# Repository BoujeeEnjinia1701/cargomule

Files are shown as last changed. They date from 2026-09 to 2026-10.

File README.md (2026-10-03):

# CargoMule

     

**Area:** Mobility and Logistics · **TRL:** 3 of 9 (proof of concept on paper) · **Value-engineering target:** $1,000 USD (a hypothetical control target, not a limit) · **Difficulty:** 3 of 5

Electric-assist cargo trailer that fits most bicycles. A load cell in the drawbar measures pull force and the trailer's hub motor pushes in proportion, so the rider feels a fraction of the load.

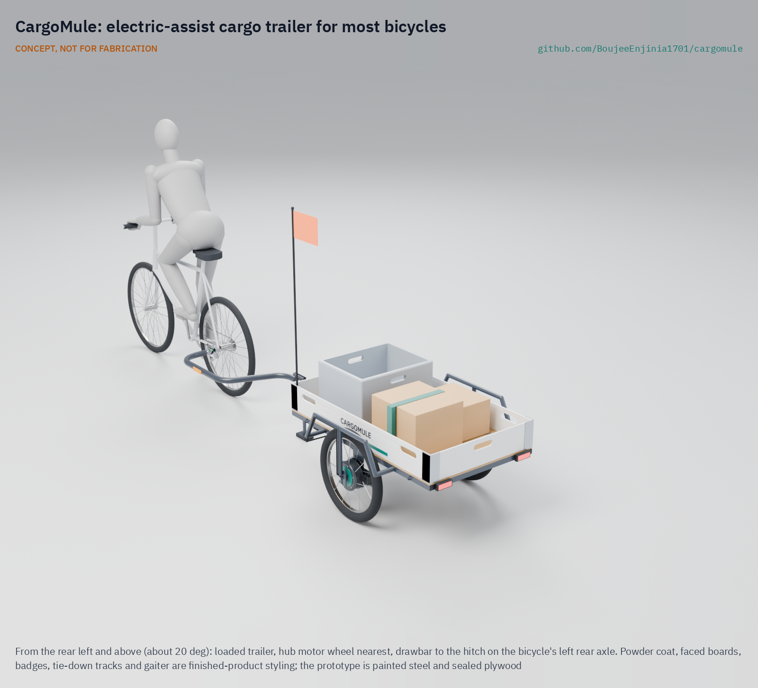
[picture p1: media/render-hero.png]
CargoMule: electric-assist cargo trailer for most bicycles, product render


[Exploded render](media/render-exploded.png) · [Detail render](media/render-detail.png) · [Interactive 3D model](media/viewer.html) · [Concept blueprint (PDF)](media/concept-blueprint.pdf) · [General arrangement (PDF)](cad/drawings/CGM-DWG-001.pdf) · [Calculations](docs/04-calcs/01-sizing.md) · [Prototype build plan](docs/05-build-plan.md) · [Design decisions](docs/06-design-decisions.md) · [Review note](docs/REVIEW.md)

## Concept rationale

Most of the cost and weight of a cargo e-bike sits in a special frame that only carries goods. CargoMule puts the load, the motor, the battery and the brakes on a trailer instead, so any household or business can turn the bicycle it already owns into a 150 kg carrier and unhitch it when the trip is done. Sensing pull force in the drawbar is what makes that possible: the trailer needs no sensor, cable or setting on the bike, it assists whoever is towing, and the same signal tells it when the bike is braking.

The design is open and garage-buildable because the people who need it most, traders, trades and community groups, are also the ones least able to pay for a commercial electric trailer. It uses a welded steel frame, plywood, a stock e-bike hub motor, cable disc brakes and a bought-in LiFePO4 pack, all parts a local welder and bike shop can source, fit and repair.

## Burning platform

Short urban trips with goods are still made mostly by car and van, and road vehicles are a large share of the problem. Transport produces [nearly a quarter of Europe's greenhouse gas emissions, and road transport emitted 73 % of the EU's transport emissions in 2023](https://www.eea.europa.eu/en/analysis/indicators/greenhouse-gas-emissions-from-transport) (European Environment Agency).

The same traffic fouls city air. The World Health Organization estimates that [ambient air pollution caused 4.2 million premature deaths worldwide in 2019, and that 99 % of the world's population lived where WHO air quality guideline levels were not met](https://www.who.int/news-room/fact-sheets/detail/ambient-(outdoor)-air-quality-and-health). Every van trip that a bicycle and trailer can take instead removes exhaust from exactly the streets where people live and shop.

## Where it could be used

### By industry

| Industry | Use |
| --- | --- |
| Market trading and street vending | Move a stall and 80 to 150 kg of stock between storage and the pitch each day |
| Building and garden trades | Carry tools, plants and materials to jobs within about 10 km without a van |
| Food banks and community groups | Collect and deliver donations with a trailer that hitches to any member's bike |
| Parcel and last-mile delivery | Extend an ordinary courier bike to bulky or heavy consignments on hilly rounds |
| Municipal services | Parks, litter and small maintenance crews working on paths where vans cannot go |
| Urban farming and allotments | Haul compost, harvests and water between plots and markets |

### By country or region

| Country or region | Why it matters there |
| --- | --- |
| Germany | Electric-assist cargo trailers are already sold under EU pedelec rules, but at a premium: the eCARLA starts at [€6,490](https://www.carlacargo.de/products/ecarla). An open design brings the idea to smaller users |
| Netherlands | The Dutch own about 1.3 bicycles per person and make 28 % of all journeys by bicycle, yet cargo bikes were only 2 % of new e-bike sales ([KiM Netherlands Institute for Transport Policy Analysis, *Cycling Facts 2023*](https://english.kimnet.nl/site/binaries/site-content/collections/documents/2024/01/10/cycling-facts-2023/KiM+brochure+Cycling+facts+2023_def.pdf)); an assisted trailer puts heavy loads on the bikes people already own |
| United States | A mainstream cargo e-bike such as the RadWagon 5 lists at [$2,399](https://www.radpowerbikes.com/products/radwagon-electric-cargo-bike) (Rad Power Bikes); a trailer for an existing bike is a cheaper entry, within the federal [low-speed electric bicycle definition](https://www.law.cornell.edu/uscode/text/15/2085) for the motor rating |
| India | Street vending is a recognized livelihood under the [Street Vendors Act, 2014](https://www.indiacode.nic.in/handle/123456789/2124?view_type=browse); an assisted trailer could help vendors move a stall and its stock to the pitch |
| Uganda and East Africa | A World Bank case study in eastern Uganda found bicycle traders carrying loads of around 100 kg of bananas and millet beer to market, pushing rather than riding up hills ([Malmberg Calvo, 1994](https://www.ssatp.org/sites/default/files/publication/SSATPWP12.pdf)); assist on hills and a braked trailer widen the loads a rider can move safely |
| Colombia (Bogotá) | Bogotá's 2023 mobility survey counted 886,655 bicycle trips a day, 7 % of all trips ([Secretaría Distrital de Movilidad](https://www.movilidadbogota.gov.co/en-bogota-el-70-de-los-viajes-diarios-se-realizan-en-modos-sostenibles-segun-encuesta-de-movilidad)); an assisted trailer lets those riders take on goods trips as well |

## What sparked the idea

The idea traces back to the EU-funded CycleLogistics project, whose 2013 baseline study of European cities concluded that [every second motorized trip in urban areas that involves goods transport could be shifted to the bicycle, and 42 % of all motorized trips in all](https://www.cargobike.jetzt/wp-content/uploads/2021/03/2013_cyclelogistics_baseline_study.pdf) (Reiter and Wrighton, FGM-AMOR). The study set the limit at the load a bicycle can carry, 80 to 200 kg for commercial cycles, and most of the potential it found lay in private trips such as shopping. That points at a gap: the loads are within reach of a bicycle, but most people own an ordinary bike, not a cargo bike. CargoMule is an attempt to close it with a trailer that brings the motor, battery and brakes to the bike the rider already has.

## Problem

Small businesses and households need to move 100 to 150 kg loads short distances, but cargo e-bikes are costly and ordinary bikes cannot pull that weight up hills.

## Concept

A two-wheel, 150 kg trailer hitches to the bicycle's left rear axle end with no wiring to the bike. An S-type load cell in the drawbar coupling measures pull force, and a 250 W geared hub motor in one trailer wheel pushes with four times that force (the rider can select 2 to 6), so the rider feels about 6.5 N on the flat and about 39 N on an 8 % grade. When the bike slows, the drawbar goes into compression, the motor cuts out and a mechanical overrun coupler applies disc brakes on both trailer wheels. TRL 3 calculations give about 24.5 km per charge on a hilly loaded route and an estimated parts cost of $1,004 against the $1,000 value-engineering target ($4 over). Made buildable, the empty trailer weighs about 46.3 kg, within the 47 kg cap Amish set for the first prototype on 2026-10-02; it is weighed at TRL 4. The hill climb (motor heating, handled by thermal derating and a stated use limit of about 300 m of continuous 8 % climbing), wet braking and hitch fit are still at risk.

Design precis: [docs/02-concept.md](docs/02-concept.md) · Calculations: [docs/04-calcs/01-sizing.md](docs/04-calcs/01-sizing.md) · Decisions: [DDR-001](docs/decisions/0001-trl2-review-decisions.md), [DDR-002](docs/decisions/0002-recommendations-accepted.md), [DDR-003](docs/decisions/0003-design-for-construction.md), [register](docs/06-design-decisions.md)

## Key components

- Welded steel trailer frame with a 1,200 x 700 mm plywood deck and wheel arch frames
- Universal axle hitch for quick-release and thru-axle bikes, with a 3.9 kN safety strap
- Bent 38 mm drawbar that clears the bike's rear tyre to 55° of yaw and slides in the coupler
- S-type load cell inside the coupler housing, with HX711-class amplifier and a 0.7 Hz assist filter
- Overrun brake coupler (spring, 7.7:1 lever, cable splitter) driving mechanical disc brakes (180 mm rotors, metallic pads) on both wheels
- 250 W, 36 V geared hub motor in one 20 in wheel, plus an idler wheel
- 36 V sine-wave motor controller (15 A pack, 30 A phase) and a microcontroller control board
- 36 V class LiFePO4 pack, 384 Wh, with BMS
- Lights, reflectors, flag and parking stand
- Battery enclosure bolted under the deck, with a lockable front door

The bill of materials is in [bom/bom.csv](bom/bom.csv). The parametric model is [cad/src/model.py](cad/src/model.py), with STEP files in `cad/step/` and the general arrangement drawing CGM-DWG-001 in `cad/drawings/`.

## Building the prototype

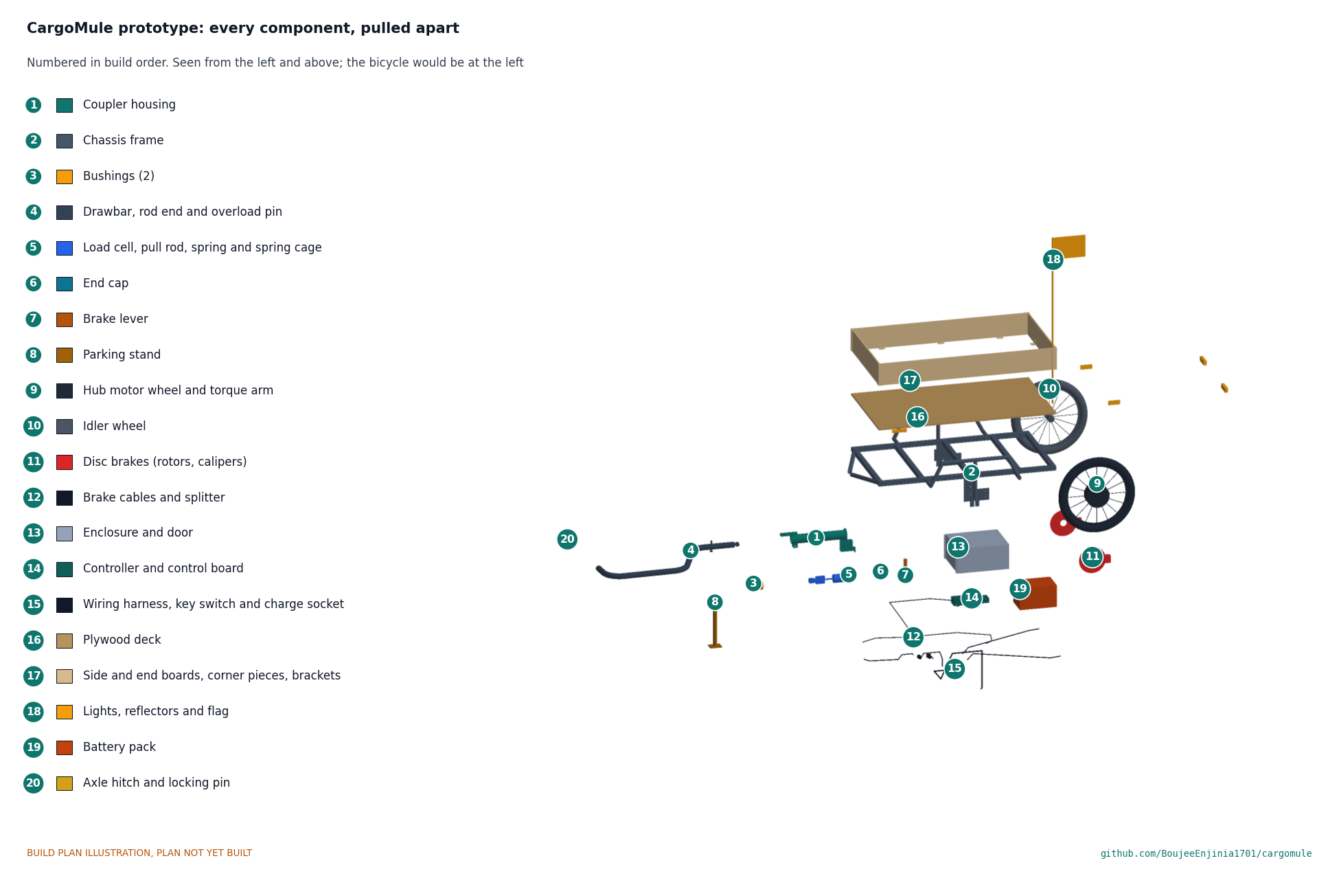
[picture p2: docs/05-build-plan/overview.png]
CargoMule prototype: every component pulled apart and numbered in build order


The [prototype build plan](docs/05-build-plan.md) (CGM-BLD-001) shows, in pictures, how to make each of the twenty components and put them together in sixteen steps; nothing has been built yet. The made parts are a steel coupler housing and spring cage, a welded box-section frame with dropout plates and arch frames, a bent drawbar, a brake lever, a parking stand, a plywood deck and boards with aluminium fittings, and a folded steel battery enclosure; the wheels, brakes, load cell, battery and electronics are bought. Writing the plan made the design buildable: the load cell now sits inside the coupler housing so the drawbar's weight goes through bushings, the coupler can be assembled in one order, the enclosure has a door and hangs from two crossmembers, and every part has a fixing (CGM-DDR-003, accepted by Amish on 2026-10-02). The constructable trailer weighs about 46.3 kg, within the 47 kg prototype cap; the key switch and charge socket sit on the enclosure's right wall, and a reflector is clamped to the drawbar. Decisions made and still open are in the [design decisions register](docs/06-design-decisions.md).

## Safety

> **Safety:** Use the trailer on private ground only until a written legal check of electrically assisted trailers exists for your country. The trailer must brake itself: at 150 kg it is well above the 45 to 60 kg limits for unbraked cycle trailers in ASTM F1975 and EN 15918. The controller must cut assist whenever the drawbar goes into compression, at standstill, above 25 km/h and on any sensor fault. Use a hitch with a secondary safety strap rated 3.9 kN or more, and keep the load centered on the marked zone so the drawbar never lifts. The trailer contains a lithium (LiFePO4) battery pack: use a BMS with cell-level protection, fuse the pack, and charge on a non-combustible surface. See the safety section of the [design precis](docs/02-concept.md).

## Repository layout

| Folder | Contents |
| --- | --- |
| `docs/` | Problem, concept, requirements, calculations and design decisions |
| `cad/src/` | build123d Python source, the source of truth for all geometry |
| `cad/step/`, `cad/stl/` | Exported models for FreeCAD, other CAD tools and printing |
| `cad/drawings/` | 2D sketches and dimensioned drawings |
| `bom/` | Bill of materials |
| `electronics/` | KiCad schematics and PCB layouts |
| `firmware/` | Microcontroller code |
| `media/` | Renders, perspectives and photos |
| `build-log/` | Dated prototyping notes |

## Documentation

Controlled documents follow the portfolio [documentation standard](.kit/STANDARDS.md). Each carries a document ID (CGM-PRC-001 for the precis), a version and a revision history. Branded PDFs are built with `python .kit/render.py` and attached to GitHub Releases when a document is tagged, for example `CGM-PRC-001/v1.0`.

## Credits

Designed by Amish Chadha. See [CONTRIBUTORS.md](CONTRIBUTORS.md) for roles. To cite this design, use [CITATION.cff](CITATION.cff) (GitHub shows it as "Cite this repository").

AI assistance (Claude) was used to accelerate concept renders, prototype documentation and first-pass sizing calculations. Design direction and all decisions are Amish Chadha's, recorded in this repository's decision records (`docs/decisions/`).

## Licenses

- **Hardware** (CAD, drawings, BOM, electronics): [CERN-OHL-S v2](LICENSE)
- **Software** (firmware, scripts, notebooks): [MIT](LICENSE-SOFTWARE)

A project of the [Design Molecule](https://designmolecule.com) lab.

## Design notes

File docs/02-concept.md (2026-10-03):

---
doc_id: CGM-PRC-001
title: CargoMule design precis
project: CargoMule
doc_type: Design precis
version: "0.8"
status: Draft
date: '2026-10-02'
author: Amish Chadha
license: CERN-OHL-S-2.0
revisions:
- version: "0.1"
  date: '2026-09-24'
  author: Amish Chadha
  change: Initial scaffold
- version: "0.2"
  date: '2026-09-25'
  author: Amish Chadha
  change: Populate to TRL 2 (architecture, control law, first-order numbers, braking, safety, media)
- version: "0.3"
  date: '2026-09-25'
  author: Amish Chadha
  change: TRL 3. Record Amish's decisions (CGM-DDR-001); numbers checked against CGM-CAL-001; offset drawbar, 0.7 Hz assist filter, wheel arch frames, 12 mm deck; parametric model and drawing CGM-DWG-001
- version: "0.4"
  date: '2026-09-25'
  author: Amish Chadha
  change: Recommendations accepted by Amish (DDR-002). 180 mm rotors with metallic pads, R8 at 45 kg, motor thermal derating rule and use limit, gain range kept at 2 to 6; numbers from CGM-CAL-001 v0.2
- version: "0.5"
  date: '2026-10-01'
  author: Amish Chadha
  change: Constructable design (CGM-DDR-003). Load cell inside the coupler housing, bent drawbar, enclosure with a front door between two crossmembers, fixings; numbers from CGM-CAL-001 v0.3; R8 now not met
- version: "0.6"
  date: '2026-10-01'
  author: Amish Chadha
  change: Budget treated as a value-engineering target; cost wording only, no number changed
- version: "0.8"
  date: '2026-10-02'
  author: Amish Chadha
  change: "Decisions of 2026-10-02: R8 47 kg prototype cap (met on paper), controls on the enclosure's right wall, friction damping with a TRL 4 chatter check, first candidate user type, private ground only until a legal check"
- version: "0.8"
  date: '2026-10-02'
  author: Amish Chadha
  change: "Figures from CGM-CAL-001 v0.6: key switch, charge socket and drawbar reflector carried into the design; empty 46.3 kg; parts $1,004, $4 over the value-engineering target"
---

# CargoMule design precis

CargoMule is a two-wheel, 150 kg cargo trailer that hitches to a bicycle's rear axle and pushes itself. A load cell inside the drawbar coupling measures how hard the bicycle pulls, a small controller commands a 250 W geared hub motor in one trailer wheel to push with four times that force, and the rider feels a fraction of the trailer's load. When the bicycle slows, the drawbar goes into compression: the controller cuts the motor and a mechanical overrun coupler applies disc brakes on both trailer wheels. TRL 3 calculations (CGM-CAL-001 v0.6) give about 24.5 km per charge of a 384 Wh LiFePO4 pack on a hilly loaded route, about 6.5 N of felt pull on the flat and about 39 N on an 8 % grade, and parts estimated at $1,004 against the $1,000 value-engineering target ($4 over). Made buildable (CGM-DDR-003, build plan CGM-BLD-001), the empty trailer weighs about 46.3 kg, within the 47 kg cap Amish set for the first prototype on 2026-10-02 (R8, CGM-DDR-003 A1); it is weighed at TRL 4. The hill climb, braking and hitch fit are still at risk (R3, R6, R7).

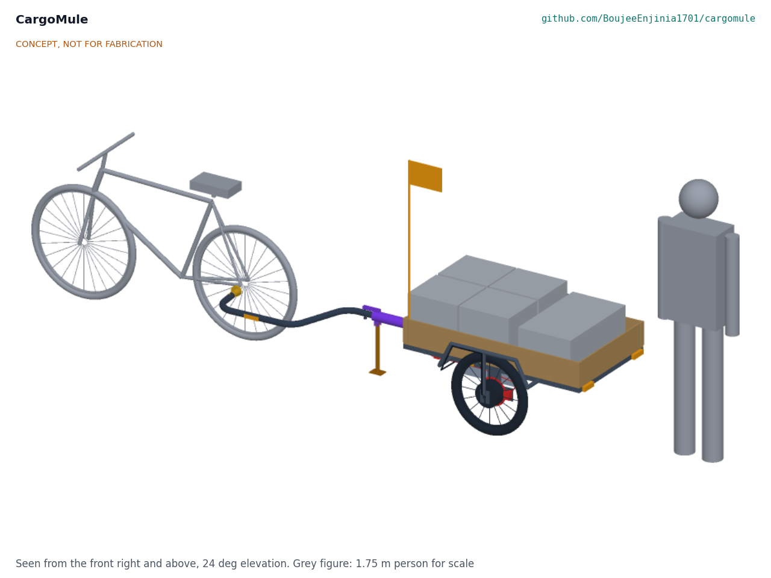
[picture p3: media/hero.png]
Hero render


*Figure 1. CargoMule hitched to an ordinary bicycle with a 150 kg load, and a 1.75 m person for scale. Trailer parts are colored; the bicycle and load are grey. Generated from the parametric model; not for fabrication.*

## How it works

1. **Hitch.** A universal hitch clamps under the bicycle's left rear axle end (quick release or thru-axle) and joins the drawbar through a joint that allows pitch, yaw and roll, so the bike can lean and turn freely. Nothing else attaches to the bike and there is no cable. The drawbar runs out 360 mm to the left before turning in, so it clears the bike's rear tyre up to 55° of yaw.
2. **Sense.** Near the trailer, the drawbar runs straight along the center line and slides in two bushings in the coupler housing, a steel tube at the frame's nose. The bushings carry bending and the tongue load; inside the housing the axial force passes through an S-type load cell and a pull rod to a bulkhead, so the cell reads only pull (tension) or push (compression). A pin through the drawbar rides in a slot on the housing: it stops the drawbar turning and, 0.5 mm from the slot's end, is the cell's overload stop. A 24-bit amplifier (HX711 class) samples at 80 Hz.
3. **Decide.** The control board filters the signal with a second-order 0.7 Hz low-pass to remove the pulse of each pedal stroke and road bumps, then sets motor force to a gain G times the measured pull above a 3 N deadband. The rider selects G from 2 to 6 on the trailer; with the default G = 4 the rider supplies about 1/(1 + G), or 20 %, of the force needed to move the trailer. The board also reads wheel speed from the motor's Hall sensors and a key switch. A firmware rule derates motor current on a winding temperature estimate so the winding stays at or below 100 °C on long climbs (CGM-DDR-002).
4. **Push.** A 36 V sine-wave controller (15 A pack and 30 A phase current limits, torque-mode input) drives a 250 W geared hub motor laced into the left 20 in wheel. The right wheel is an idler. Assist stops above 25 km/h, when the trailer stands still and whenever the drawbar is not in tension.
5. **Brake.** When the bicycle brakes, the trailer's momentum pushes the drawbar into compression. A fast path on the raw load cell signal zeroes the motor within about 60 ms once compression passes 20 N. Beyond a 30 N preload, the drawbar, load cell and pull rod slide back against a spring, and the pull rod's tail pushes a 7.7:1 lever (with friction damping on its pivot) that pulls cables to mechanical disc brakes with 180 mm rotors and metallic pads on both wheels, as in a car trailer's overrun brake. The brakes work with the electronics off or failed.
6. **Store and charge.** A 12S LiFePO4 pack (38.4 V nominal, 10 Ah, 384 Wh) with its own BMS sits in a closed steel enclosure hung under the deck between two crossmembers, beside the controller and control board; it slides out through a lockable front door. It charges from a 43.8 V, 4 A charger off the trailer in about 3 h.

Sensing force at the drawbar is what lets CargoMule fit most bicycles without wiring: it does not need to know how hard the rider pedals, only how hard the bike pulls. It also detects braking, since a pushing drawbar means the bike is slowing.

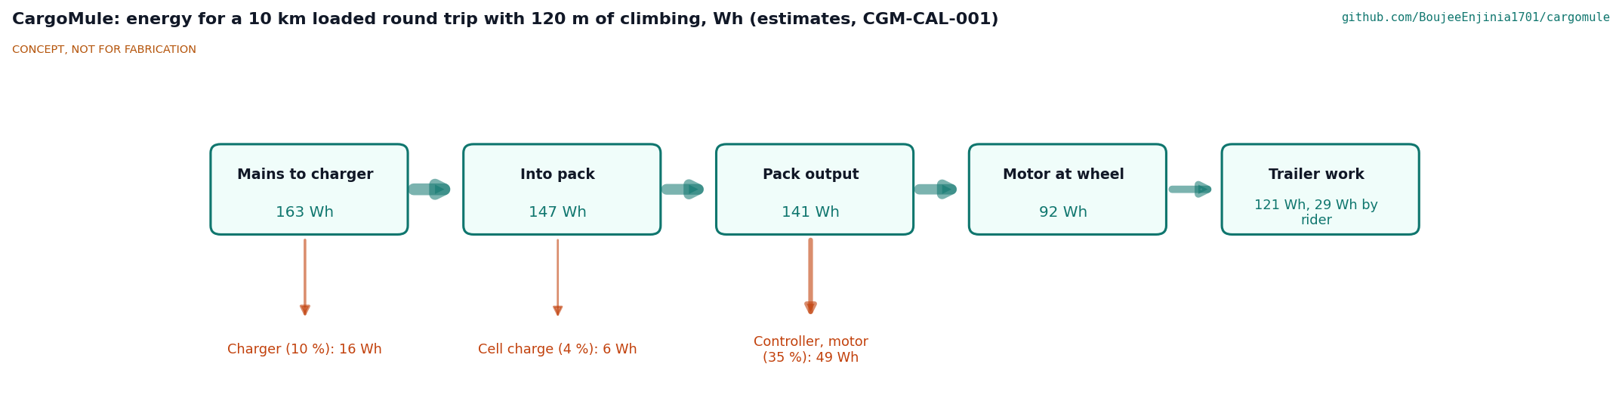
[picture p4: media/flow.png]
Energy flow


*Figure 2. Energy for one 10 km loaded round trip with 120 m of climbing and 20 stops, in Wh (CGM-CAL-001, E6). All values are estimates.*

## Main components

Numbers match the exploded view (Figure 3) and `bom/bom.csv`. The general arrangement is drawing CGM-DWG-001 (`cad/drawings/CGM-DWG-001.pdf`), generated from `cad/src/model.py`.

Table 1. Main components.

| # | Component | Choice | Notes |
| --- | --- | --- | --- |
| 1 | Chassis frame | Welded mild steel: 30 x 30 x 1.5 mm box perimeter and three crossmembers, A-frame nose, wheel arch frames carrying the outer dropouts, dropouts for 100 mm hubs | Steel (CGM-DDR-001, D3); about 12.4 kg |
| 2 | Deck and side boards | 12 mm exterior plywood deck, 1,200 x 700 mm; removable 9 mm side boards, 150 mm high | Tie-down eyes on the frame |
| 3 | Drawbar | S355 tube 38 x 2.5 mm, bent in three 115 mm radius bends, offset 360 mm left of the center line, straight rear part sliding in the coupler | Upsized from 32 x 2 mm for the offset |
| 4 | Universal axle hitch | Plate under the axle end with a three-axis joint, lock indicator and a secondary strap rated 3.9 kN or more | QR and thru-axle adapters |
| 5 | Drawbar load cell and amplifier | S-type cell, 1 kN (100 kg) range, inside the coupler housing on a clevis and pull rod, overload stop, HX711-class amplifier | Reads axial force only |
| 6 | Overrun brake coupler | Steel housing welded into the frame nose, two bushings, spring cage and end cap, 50 mm stroke, 30 N preload, 7.7:1 lever with friction damping, cable splitter | Mechanical; works with power off |
| 7 | Hub motor wheel | 36 V, 250 W geared front-style hub, about 230 rpm winding, 20 in (ETRTO 406) wheel, disc mount | Left side (CGM-DDR-001, D4) |
| 8 | Idler wheel | 20 in wheel with a 100 mm disc hub, salvaged or budget grade | Right side |
| 9 | Mechanical disc brakes | Two budget cable calipers, 180 mm rotors, metallic (sintered) pads | Actuated by item 6; 180 mm per CGM-DDR-002 (was 160 mm) |
| 10 | Battery and electronics enclosure | Folded 0.8 mm galvanized steel, 350 x 300 x 170 mm, vented, lockable front door | Bolted under two crossmembers; 208 mm ground clearance |
| 11 | Battery pack | 12S1P LiFePO4, 38.4 V, 10 Ah, 384 Wh, with BMS | 36 V LFP (CGM-DDR-001, D2) |
| 12 | Motor controller | 36 V sine wave, 15 A pack and 30 A phase limits, torque-mode input, IP65 | Commanded by item 13 |
| 13 | Control board | Microcontroller, load cell input, Hall speed input, key switch, gain selector, status LED | Firmware is a TRL 3 sketch at most |
| 14 | Wiring harness | Keyed waterproof connectors, 20 A fuse, key switch and 3-pin charge socket on the enclosure's right wall near the front | |
| 15 | Lights, reflectors and flag | Rear red lights powered from the pack, side reflectors, an amber drawbar reflector, flag on a pole at the front left corner, top at 1,570 mm | |
| 16 | Parking stand | Leg pivoted under the coupler housing, folds back | Holds the coupler level when unhitched |

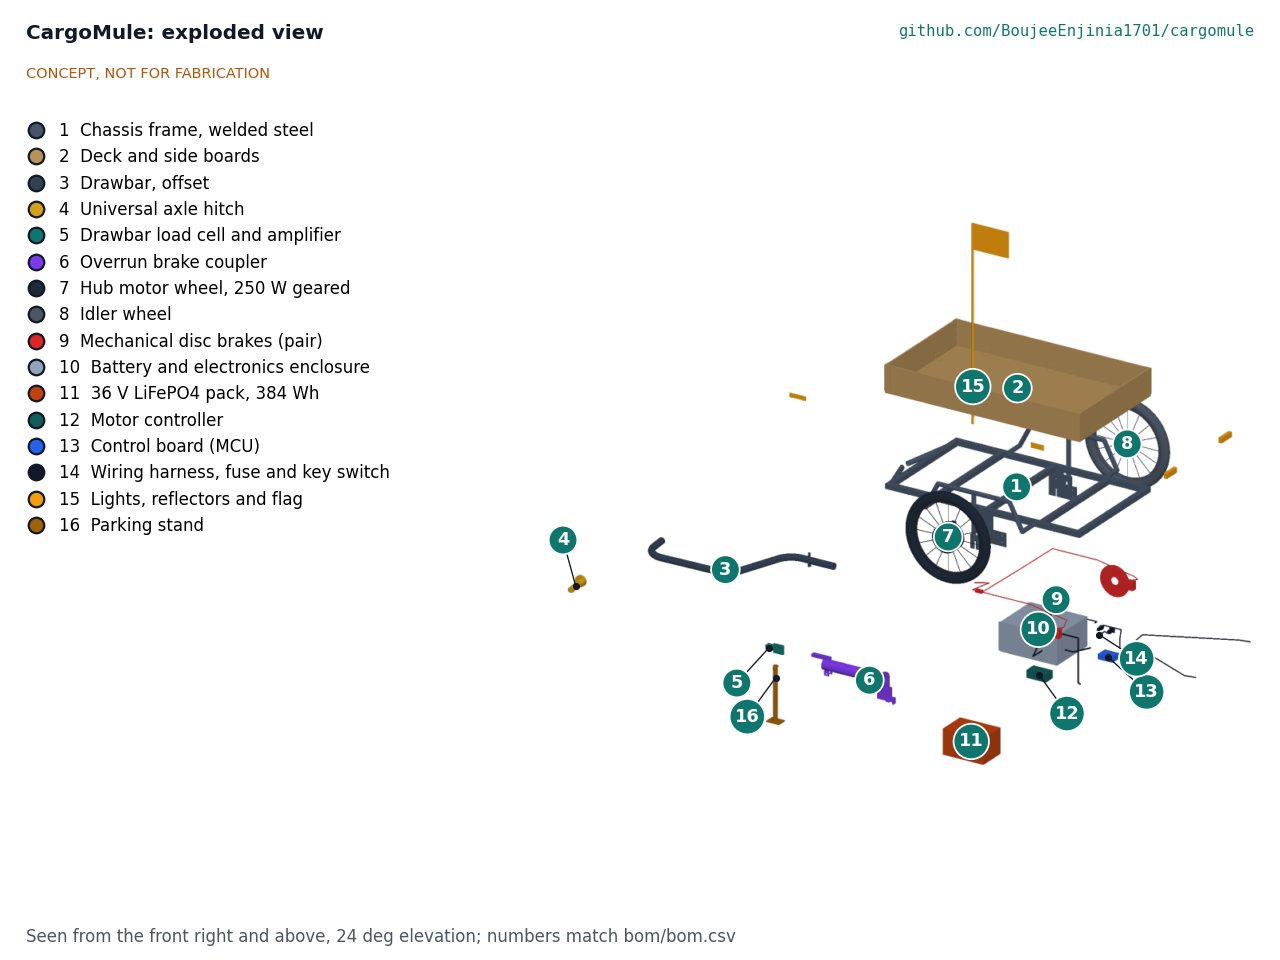
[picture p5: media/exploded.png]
Exploded view


*Figure 3. Exploded view with numbered callouts matching the BOM.*

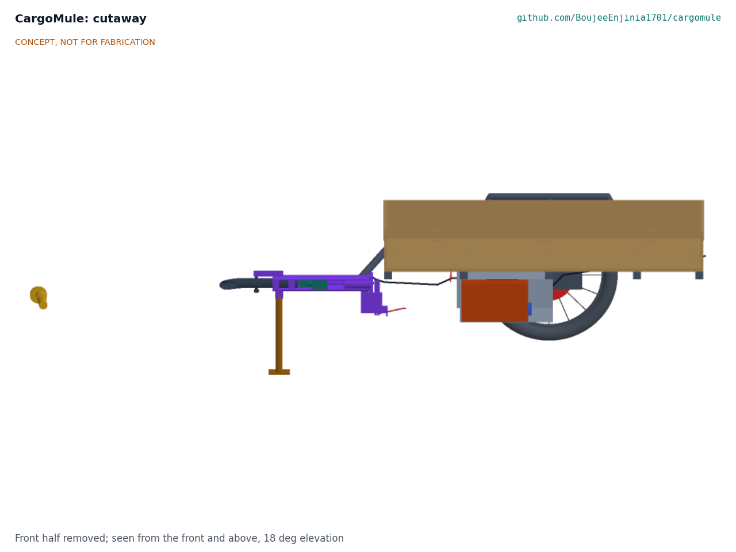
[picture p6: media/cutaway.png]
Cutaway


*Figure 4. Section on the trailer's center line, showing the pack, controller and control board in the enclosure under the deck, and the load cell and overrun coupler on the drawbar.*

## Checked numbers

All values come from CGM-CAL-001 and its script `docs/04-calcs/sizing.py`; the tag in brackets is the script line. Assumptions are listed there and in CGM-REQ-001.

### Mass and balance

Table 2. Mass and balance.

| Group | Value |
| --- | --- |
| Frame 13.0 kg, deck, boards and fittings 8.9 kg, drawbar, hitch, load cell and coupler 6.9 kg, stand 0.6 kg | 29.4 kg |
| Wheels, motor, torque arm and brakes | 7.3 kg |
| Enclosure, pack, controller, board, harness with key switch and charge socket | 8.3 kg |
| Lights, reflectors (with the drawbar reflector), flag, hardware and paint | 1.4 kg |
| **Empty trailer** | **46.3 kg (102 lb) [A3]; R8 (47 kg prototype cap) met on paper** |
| Loaded trailer, design case | 196.3 kg [A4] |
| Hitch down load, payload centered | 7.5 kg [A6]; axle 20 mm behind the deck center; R10 met |
| Loading window for 3 to 10 kg on the hitch | payload center 32 mm ahead to 57 mm behind the deck center [A7] |
| Static rollover threshold | 0.77 g on the 800 mm track [A8] |

Without the side boards the trailer weighs 43.5 kg. Amish decided on 2026-09-25 to relax R8 to 45 kg for the first prototype, keep the steel frame (CGM-DDR-001, D3) and hold straps or mesh in place of the side boards as a later weight option (CGM-DDR-002). Making the design buildable added 3.0 kg (CGM-DDR-003), mostly in the coupler. On 2026-10-02 Amish set R8 to 47 kg as a hard cap for the first prototype only (A1); the trailer is weighed at TRL 4, and straps or mesh replace the side boards if it is over 47 kg. The key switch, charge socket and drawbar reflector decided the same day add about 0.1 kg, leaving 0.7 kg under the cap.

### Forces, motor and heating

Table 3. Drawbar forces with G = 4 and a 3 N deadband.

| Case | Trailer resistance | Motor force | Felt by rider | Motor | Requirement |
| --- | --- | --- | --- | --- | --- |
| Flat, 5 to 20 km/h | 19.4 to 21.1 N | 13.1 to 14.5 N | 6.3 to 6.6 N [B1] | | R4 (15 N) met |
| 8 % grade at 8 km/h | 173.6 N [B2] | 134.9 N | 38.7 N [C3] | 300 W, 24.3 A phase, 15.0 A pack [C2] | R3 force (40 N) met |
| Same grade, no assist | 173.6 N | 0 | 173.6 N, 386 W extra | | Why assist is needed |

The motor runs at about 55 % efficiency on the climb, so it loses about 247 W. After flat cruising the winding sits near 52 °C; the 300 m design climb brings it to about 96 °C against a 100 °C limit, and a 1,000 m climb would reach about 175 °C [C6]. R3 is therefore at risk. Amish decided to keep the 250 W motor, add thermal derating and state a use limit (CGM-DDR-002): at full assist the winding reaches 100 °C after about 331 m of 8 % climbing, after which the firmware holds it there by cutting current, and the felt pull rises toward about 117 N on a climb that never ends [C10]. The rider instructions state a use limit of about 300 m of continuous 8 % climbing with full assist. The motor constants still need a datasheet, which comes with part selection at TRL 4 (on hold). The result also depends on the controller: with a 12 A pack limit the rider would feel 59 N [C4]. Assisted or not, the rider still lifts their own bike and body; at 150 W a rider climbs the 8 % grade at about 4.4 km/h [C5].

The motor drives only the left wheel, so on the climb it applies a yaw moment of about 135 N x 0.40 m, about 54 N·m, reacted mostly by the tyres. This should be small in practice but is unverified for handling on gravel or in the wet.

### Assist loop stability

The drawbar, hitch joint and load cell act as a spring between the bike and the trailer, and the motor feeds the measured pull back with a delay of about 39 ms [D1]. The TRL 2 filter (first order, 2 Hz) makes this loop oscillate above G = 0.5 at the softest stiffness considered. A second-order 0.7 Hz filter is stable for G = 2 to 6 across drawbar stiffnesses of 20 to 500 N/mm, with a gain margin of 2.9 (9.3 dB) at G = 4 and 2.0 (5.8 dB) at G = 6 [D3]. Amish decided to keep 2 to 6 on paper and to settle the top setting once the hitch joint stiffness is measured, which is TRL 4 work and on hold (CGM-DDR-002). The price is a slower assist: about 0.47 s to reach 90 % after a step in pull [D4]. The compression cut does not wait for the filter; it acts on the raw signal in about 60 ms [D6].

### Energy and range

Table 4. Energy on the design route (10 km, 120 m up and down, 20 stops).

| Quantity | Value | Basis |
| --- | --- | --- |
| Flat, 5.2 km at 18 km/h | 27 Wh from the pack | [E1] |
| Climbs, 2.4 km at 5 % and 10 km/h | 96 Wh | [E1]; motor at low efficiency |
| Descents, 2.4 km | 0 Wh | Overrun brake holds speed |
| Stops, 20 from 18 km/h | 18 Wh | [E2] |
| **Pack energy per km** | **14.1 Wh/km** | [E3] |
| Usable pack energy | 346 Wh | 384 Wh x 90 % |
| **Range on the design route** | **24.5 km** | R2 (20 km) met [E3] |
| Range on flat roads, few stops | about 61 km | 5.7 Wh/km [E4] |
| Mains energy per 10 km trip | 163 Wh | Figure 2 [E6] |
| Charge time, empty to full | about 3 h | 10 Ah at 4 A plus the constant-voltage phase [E7] |

### Braking

At 20 km/h the loaded trailer carries 3.03 kJ of kinetic energy, about twice the bicycle and rider (1.54 kJ). For the combination to slow at 3 m/s², the trailer needs 589 N of braking force; with the bike taking at most 100 N of push, the trailer brakes must give 489 N [F1]. Amish decided on 2026-09-25 to fit 180 mm rotors with metallic pads (CGM-DDR-002). With the same overrun coupler (30 N preload, 7.7:1 lever, 27 mm of its 50 mm stroke used to take up clearance) the brake gain rises from 6.9 to 7.8, so the push is 93 N with dry pads [F3] and about 111 N with wet pads, against 121 N with 160 mm rotors [F4]. R6 is improved but still at risk in the wet. Stopping distance from 20 km/h is 10.7 m with a 1 s reaction [F5]. On a long 8 % descent at 20 km/h the rider feels about 42 N of push and each rotor absorbs about 258 W, tending to a temperature rise of about 131 K; on 10 % at 25 km/h this becomes about 225 K [F6]. A descent speed limit is still needed.

### Structure and fit

- Side rails: 149 MPa at a 2 g bump, a factor of 1.6 on S235 [G1]. Drawbar: a factor of 4.3 at a 3 g tongue load, taken at the coupler's front bushing, and 1.6 in the ultimate hitch case of 1,926 N [G3], [G4]. Hitch axle: factors of 2.4 (QR) and 3.8 (thru-axle); safety strap 3.9 kN or more [G6]. Deck: 8.4 MPa under a 75 kg point load against 10 MPa allowable [G7].
- Overall 960 mm wide (972 mm over the motor cable clipped outside the left arch) and 2.52 m long from the bike axle [H2]; tyre to side rail 22.5 mm [H3]; articulation 55.5° toward the drawbar side and 105.5° away from it [H5], enough for steady turns down to about 1.3 m radius [H6].

### Cost

Table 5. Parts cost from `bom/bom.csv` (CGM-CAL-001, I1).

| Group | Items | Cost |
| --- | --- | --- |
| Structure | 1 to 4, 16 | $272 |
| Sensing and braking | 5, 6, 9 | $135 |
| Drive | 7, 8, 12 | $225 |
| Energy and control | 10, 11, 13, 14, 17 | $309 |
| Lights and hardware | 15, 18 | $63 |
| **Total** | | **Value-engineering target: USD 1,000. Estimated cost of the constructable design: USD 1,004 (USD 4 over the target; R12)** |

The D1 cost cuts (salvaged or budget idler wheel, budget calipers, smaller enclosure) save $50; the TRL 3 changes (arch frames, repriced plywood, the larger offset drawbar, a stronger hitch strap, the coupler lever and the load cell overload stop) add $54. The 180 mm rotors and metallic pads of CGM-DDR-002 add $10, and the fittings and coupler parts of CGM-DDR-003 add $18. The decisions of 2026-10-02 add $7: a 3-pin charge socket with a hinged cap (about $4) and the drawbar reflector (about $3).

## Key design choices

Amish decided the choices below on 2026-09-25 (CGM-DDR-001 and CGM-DDR-002), in each case going with the recommendation.

- **Force sensing at the drawbar (D8).** No sensor on the bike, works with most bikes and riders, and detects braking. Alternatives were a crank sensor on the bike or wheel-speed matching.
- **Control law (D5).** Proportional assist, motor force = G x measured pull, with a rider-selectable gain of 2 to 6 and a default of 4. TRL 3 adds the 0.7 Hz second-order filter and the 3 N deadband that keep this loop stable and quiet.
- **One hub motor in the left wheel (D4).** Cheapest, one controller, small yaw moment.
- **Overrun mechanical brake plus assist cut (D6).** Works unpowered; known from car trailers and Carla Cargo.
- **Battery (D2).** A 12S 36 V class LiFePO4 pack, 384 Wh. A SwapCell receiver is a later fleet variant; it would build to SwapCell interface v0.3 (wake without CAN, charge while discharging, vehicle latch vibration rating), and the shared pack would be priced once and left out of this kit's budget.
- **Frame material (D3) and mass target (DDR-002).** Welded mild steel for the first prototype, with R8 relaxed to 40 kg and then to 45 kg. The constructable trailer weighs 46.3 kg (CGM-DDR-003); on 2026-10-02 Amish set R8 to 47 kg as a hard cap for the first prototype (A1). Straps or mesh in place of the side boards are the fallback if the weighed trailer is over the cap.
- **Long climbs (DDR-002).** Keep the 250 W motor, derate current on winding temperature and state a use limit of about 300 m of continuous 8 % climbing.
- **Brakes (DDR-002).** 180 mm rotors with metallic pads on both wheels, with the 7.7:1 coupler lever kept.
- **Gain range (DDR-002).** Keep G = 2 to 6 on paper; settle the top setting when the hitch joint stiffness is measured (TRL 4, on hold).
- **20 in wheels and a hitch on the left axle end (D9).** Small wheels keep the deck low (420 mm) and the drawbar near level with a 700c or 26 in bike's axle; the left side keeps clear of the derailleur.
- **Value-engineering target (D1).** Cost cuts first, then `budget_usd` raised to $1,000 as a hypothetical control target, not a limit.
- **Handcart mode (D10).** Out of scope for now.

- **Controls and damping (CGM-DDR-003, A2 and A3, 2026-10-02).** Key switch and charge socket on the enclosure's right wall near the front, with their leads kept inside the box so none crosses the door's hinge; friction washers on the brake lever pivot, with a rough-road chatter check as a TRL 4 pass condition and the small hydraulic damper fitted if the brake chatters or grabs.
- **First users (O1, 2026-10-02).** Chosen by one rule: a group moving 50 to 150 kg loads on short, repeated urban trips on paved, hilly routes. The first candidate type to approach is a community food bank's local delivery or pantry runs; nothing is agreed with any partner.
- **Road use (O2, 2026-10-02).** Private ground only until a written legal check exists for the first partner's country; the EU pedal-assist limits stay the design rule.

Every decision is listed in the design decisions register, CGM-DEC-001 (`docs/06-design-decisions.md`).

## Safety

> **Safety:** CargoMule is a 196 kg moving load behind a bicycle, driven by a motor and powered by a lithium battery. Braking, hitch failure, runaway assist, motor and brake heat, and battery fire are the main hazards, and each must be designed out before any ride.

- **Runaway or unintended push.** A motor that pushes when the bike slows can shove the bike into traffic or jackknife it. Assist only while the drawbar is in tension above the 3 N deadband; zero motor current within 100 ms of compression above 20 N (about 60 ms on paper, on the raw signal), above 25 km/h, at standstill, on any load cell fault (open or short, out of range, stuck value, failed plausibility check against speed) and when the key is off. The controller must run in torque mode with its own current limit, so a firmware fault cannot command more than the rated force. No throttle.
- **Assist oscillation.** With the TRL 2 filter the assist loop would oscillate and could pump the drawbar. The 0.7 Hz second-order filter is required, and gains above 6 must not be selectable.
- **Braking and jackknife.** The loaded trailer has about twice the kinetic energy of the bicycle and rider. Trailer brakes are mandatory above the 45 to 60 kg limits in ASTM F1975 and EN 15918, and the overrun brake must work with the power off. With the 180 mm rotors and metallic pads, wet pads still raise the push on the bike to about 110 N, and long, steep descents can heat rotors by 130 to 220 K; limit descent speed.
- **Hitch failure.** A detached 196 kg trailer is a serious hazard to others. The hitch needs a secondary safety strap rated 3.9 kN or more, a clear locking indicator and a design load above the 1,926 N ultimate case.
- **Load placement.** The hitch load swings by 7.8 kg per 100 mm of payload shift, and the drawbar unloads with the payload center 96 mm behind the deck center. Mark the loading zone on the deck and strap loads down; a lifting drawbar makes the trailer unstable.
- **Motor heat.** Climbs longer than about 300 m at 8 % can overheat the motor; the firmware derates current on a winding temperature estimate, and the use limit is stated to riders. Assist fades rather than stops, so the rider must be ready to carry more of the load near the top of a long climb. The left rotor sits on the motor, so brake heat also reaches it.
- **Lithium battery.** A 384 Wh LiFePO4 pack is less prone to thermal runaway than other lithium-ion chemistries, but a short circuit can still start a fire. Use a BMS with cell-level protection and low-temperature charge cutoff, a 20 A fuse at the pack, a closed steel enclosure with a vent directed away from the load, and charge on a non-combustible surface away from sleeping areas. Never charge a damaged or wet pack.
- **Mains charging.** The charger is a certified off-the-shelf unit; no mains wiring is built into the trailer.
- **Tipping.** The static rollover threshold is 0.77 g with the design load; a high or off-center load lowers it. Keep loads low and centered.
- **Pinch points and sharp edges.** The drawbar slides 50 mm into the coupler under load, the brake lever swings under the housing and the parking stand folds; keep fingers out of the fork slot, the side window and the lever cheeks (the window has a rubber cover). Deburr all frame edges and fit end caps to open tube ends. The tyres run 22.5 mm from the side rails.
- **Visibility.** A long, wide combination is easy to misjudge; lights, reflectors and a flag are part of the design, not accessories.
- **Road use.** Until a written legal check exists for the first partner's country, use the trailer on private ground only (decided 2026-10-02, CGM-DDR-001 O2).

## Open questions

TRL 4 is on hold by Amish's instruction. These questions remain at TRL 3:

- The written legal check of a motorized bicycle trailer for the first partner's country, needed before any public road use (CGM-DDR-001, O2).
- Motor constants (winding, resistance, thermal) from a real datasheet, which decide whether R3 holds (decided, CGM-DDR-002; comes with part selection at TRL 4, on hold).
- Stiffness and damping of the hitch joint, which set the real loop margin and the top gain setting (TRL 4 measurement, on hold).
- Wet braking on long descents (R6): about 111 N of push remains with 180 mm rotors; wet pad friction data or a higher lever ratio would close the gap.
- Hitch axles for each thru-axle thread and length, and adapters for nutted axles (R7).
- Yaw effect of driving one wheel, especially on gravel or in the wet.
- Freedom to operate against coupling-sensor patents such as WO2022223692A1.

Concept media: [blueprint sheet](../media/concept-blueprint.pdf), [interactive 3D model](../media/viewer.html). General arrangement: [CGM-DWG-001](../cad/drawings/CGM-DWG-001.pdf). Prototype build plan: [CGM-BLD-001](05-build-plan.md).

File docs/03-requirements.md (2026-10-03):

---
doc_id: CGM-REQ-001
title: CargoMule requirements
project: CargoMule
doc_type: Requirements
version: "0.8"
status: Draft
date: '2026-10-02'
author: Amish Chadha
license: CERN-OHL-S-2.0
revisions:
- version: "0.1"
  date: '2026-09-24'
  author: Amish Chadha
  change: Initial scaffold
- version: "0.2"
  date: '2026-09-25'
  author: Amish Chadha
  change: First measurable requirements for TRL 2, with status against the concept estimates
- version: "0.3"
  date: '2026-09-25'
  author: Amish Chadha
  change: TRL 3. R8 relaxed to 40 kg and R12 redefined as the $1,000 budget (CGM-DDR-001); status from CGM-CAL-001
- version: "0.4"
  date: '2026-09-25'
  author: Amish Chadha
  change: Recommendations accepted by Amish (DDR-002). R8 relaxed to 45 kg; R3 restated with thermal derating and a use limit; status from CGM-CAL-001 v0.2
- version: "0.5"
  date: '2026-10-01'
  author: Amish Chadha
  change: Status from CGM-CAL-001 v0.3 for the constructable design (CGM-DDR-003); R8 now not met at 46.2 kg; no target changed
- version: "0.6"
  date: '2026-10-01'
  author: Amish Chadha
  change: Budget treated as a value-engineering target; cost wording only, no number changed
- version: "0.7"
  date: '2026-10-02'
  author: Amish Chadha
  change: "R8 restated as a 47 kg hard cap for the first prototype (CGM-DDR-003 A1, accepted 2026-10-02), now met on paper; private-ground rule for O2 noted"
- version: "0.8"
  date: '2026-10-02'
  author: Amish Chadha
  change: "Status from CGM-CAL-001 v0.6 with the 2026-10-02 decisions carried in: R8 met on paper at 46.3 kg; R12 now over the value-engineering target by $4 ($1,004); no target changed"
---

# CargoMule requirements

These requirements are checked by calculation in CGM-CAL-001 v0.6 at TRL 3, for the constructable design of CGM-DDR-003. Targets changed with Amish's decisions of 2026-09-25. Under CGM-DDR-001, R8 was relaxed from 35 kg to 40 kg for the steel frame (D3) and R12 was redefined against the $1,000 prototype value-engineering target (D1). Under CGM-DDR-002, R8 is relaxed again to 45 kg for the first prototype, and R3 is restated: the 300 m climb target stands, and beyond it the controller derates motor current to protect the winding, with the use limit stated to riders. On 2026-10-02 Amish accepted the response to the R8 miss (CGM-DDR-003, A1): R8 is 47 kg as a hard cap for the first prototype only, and the trailer is weighed at TRL 4. Against the calculations, **three are at risk (R3, R6, R7)**; eight are met on paper or by design, R12 is over its value-engineering target by $4 (a target, not a limit), and two cannot be verified at TRL 3. Targets are not yet validated with users; the first users and region for co-design are still open (CGM-DDR-001, O1).

The **design load case** is 150 kg of payload centered on the deck, the trailer (about 46 kg, CGM-CAL-001) and a towing bicycle with rider of about 100 kg, on a dry paved road. The **design route** is a 10 km round trip with 120 m of climbing, 120 m of descent and 20 stops.

Table 1. Requirements, targets and status at TRL 3.

| ID | Requirement | Target | Verification (TRL 3 or later) | Status (CGM-CAL-001) |
| --- | --- | --- | --- | --- |
| R1 | Carry the payload | 150 kg (330 lb) on a deck of at least 0.8 m², with tie-down points | Frame stress calculation; later proof load | Met on paper: deck 0.84 m²; least structural factor 1.6 at 2 g and the ultimate hitch case |
| R2 | Range per charge | 20 km or more on the design route in the design load case | Energy calculation; later logged ride | Met on paper: 24.5 km |
| R3 | Assist on hills | 8 % grade for 300 m at 8 km/h or more with the rider feeling 40 N or less of drawbar pull, without motor over-temperature at 30 °C. On longer continuous climbs the controller derates motor current so the winding stays at or below 100 °C; the use limit (about 300 m of continuous 8 % climbing at full assist) is stated in the rider instructions (restated, CGM-DDR-002) | Force and thermal calculation; motor datasheet at part selection | **At risk:** 38.7 N felt; winding about 96 °C against a 100 °C limit on assumed motor constants; derating starts after about 331 m [C10] |
| R4 | Near-zero added load on the flat | Steady drawbar pull felt by the rider 15 N or less at 5 to 20 km/h | Control calculation and simulation | Met on paper: 6.3 to 6.6 N; loop stable for G = 2 to 6 with the 0.7 Hz filter |
| R5 | Stay within pedal-assist limits | 250 W rated continuous motor output; assist only while the drawbar is in tension; no assist above 25 km/h; no throttle | Datasheets; controller settings | Met by design |
| R6 | Trailer brakes itself | With the combination slowing at 3 m/s², the trailer pushes the bicycle with 100 N or less; assist cut within 100 ms of drawbar compression above 20 N | Braking calculation; later bench test | **At risk:** 93 N dry and about 111 N with wet pads on 180 mm rotors with metallic pads (CGM-DDR-002); rotor heating on long descents; cut about 60 ms on paper |
| R7 | Hitch to common bicycles | Fits rear wheels with a 9 mm quick release or a 12 mm thru-axle, 130 to 148 mm spacing, 26 in to 700c; hitch and unhitch in 30 s or less; no wiring to the bike | Hitch design review; later fit survey | **At risk:** axle stresses pass; thru-axles need a hitch axle per thread pitch and length; nutted axles, some hub gears and some rear-motor e-bikes need adapters |
| R8 | Light enough to handle | Empty trailer 47 kg (104 lb) or less, including the pack: a hard cap for the first prototype only, not a product target (relaxed from 35 kg to 40 kg by CGM-DDR-001 D3, to 45 kg by CGM-DDR-002, then to 47 kg by CGM-DDR-003 A1 on 2026-10-02) | Mass estimate; weighing at TRL 4 | Met on paper: 46.3 kg (43.5 kg without side boards); if the weighed trailer is over 47 kg, straps or mesh replace the side boards |
| R9 | Fit bike paths and doors | Overall width 1,000 mm or less; length 2.6 m or less hitched from the bike's rear axle | Model check | Met on paper: 960 mm wide (972 mm over the motor cable), 2.52 m long |
| R10 | Stable hitch load | Downward load on the hitch 3 to 10 kg with the design payload centered | Mass and balance estimate | Met on paper: 7.5 kg; holds only for a payload center 32 mm ahead to 57 mm behind the deck center |
| R11 | Weather and temperature | Electronics IP65; motor IP54 or better; operate −10 to 40 °C; the BMS blocks charging below 0 °C | Datasheets and design review | Not verifiable at TRL 3 |
| R12 | Affordable | Prototype parts within the $1,000 value-engineering target, including charger, equal to `budget_usd` (a hypothetical control target, not a limit; redefined, CGM-DDR-001 D1) | Priced BOM (`bom/bom.csv`) | Over the value-engineering target by $4: $1,004 estimated |
| R13 | Fail safe | Loss of the load cell signal, a reading out of range, a stuck value or a controller fault sets motor current to zero within 100 ms; the trailer stays towable as an unpowered, braked trailer | Fault tree and design review | Not verifiable at TRL 3 (60 ms fast path on paper) |
| R14 | Be seen | Rear red lights and reflectors, side reflectors, and a flag at 1.5 m or more above the ground | Design review | Met by design: flag top 1,570 mm; amber drawbar reflector added (2026-10-02) |

## Assumptions

- Rolling resistance coefficient 0.010 for 20 x 2.15 in tyres on pavement at design load; extra drag area of the loaded trailer 0.1 m², since it rides partly in the rider's wake.
- Air density 1.2 kg/m³; gravitational acceleration 9.81 m/s².
- Drive efficiency from a motor model at each operating point (CGM-CAL-001, section C) rather than a fixed 75 %; charger efficiency 90 %; cell charging efficiency 96 % for LiFePO4.
- Usable pack energy 90 % of the nominal 384 Wh.
- 250 W and 25 km/h follow the EU pedal-assist exclusion (Regulation (EU) No 168/2013); the US federal definition allows more (under 750 W, 20 mph), so the EU limits are the tighter case. Whether a motorized trailer falls under either rule is unsettled in both the EU and the US. Amish decided on 2026-10-02 (CGM-DDR-001, O2) that the trailer is for private ground only until a written legal check exists for the first partner's country, and that the EU limits stay the design rule as the strictest common case.
- Brake and hitch loads follow the voluntary cycle trailer standards EN 15918 and ASTM F1975, which limit unbraked trailers to 60 kg and 45.4 kg; CargoMule exceeds both, so its brakes are required, not optional.

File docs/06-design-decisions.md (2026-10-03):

---
doc_id: CGM-DEC-001
title: CargoMule design decisions register
project: CargoMule
doc_type: Design decisions register
version: "0.5"
status: Draft
date: '2026-10-02'
author: Amish Chadha
license: CERN-OHL-S-2.0
revisions:
  - version: "0.1"
    date: '2026-10-01'
    author: Amish Chadha
    change: Register opened with the open decisions from the decision records, the review note and the build plan work
  - version: "0.2"
    date: '2026-10-01'
    author: Amish Chadha
    change: Budget treated as a value-engineering target
  - version: "0.3"
    date: '2026-10-02'
    author: Amish Chadha
    change: "Amish approved the recommendations for all eight open decisions on 2026-10-02; moved to decisions made; R8 fallback line in value engineering updated; 2026-09-26 review note items 1 to 3 closed"
  - version: "0.4"
    date: '2026-10-02'
    author: Amish Chadha
    change: "Design for construction (CGM-DDR-003, Table 1, P1 to P15) accepted by Amish on 2026-10-02; added to decisions made"
  - version: "0.5"
    date: '2026-10-02'
    author: Amish Chadha
    change: "Decisions of 2026-10-02 carried into the design: value engineering updated to USD 1,004; key switch and charge socket added to the things to confirm; one new open decision (gain selector and status light position) found while updating the appearance model"
---

# CargoMule design decisions register

Every design decision still to be made, and every decision made, in one place. Each decision is argued in full in its decision record under `docs/decisions/`; this register is the index Amish works from. The build plan (`docs/05-build-plan.md`) describes the design as it stands and does not list open decisions.

## Open decisions

All open decisions in this register were decided on 2026-10-02. One new point was found on 2026-10-02 while carrying those decisions into the design:

| # | Decision | Options | Recommendation | What it affects in the build | Source |
| --- | --- | --- | --- | --- | --- |
| 9 | Where the assist gain selector (G = 2 to 6) and the status light go. The 2026-09-26 renders put them on the enclosure's front face, which is now the door; the BOM puts them on the control board inside the locked box, where the rider can neither see the light nor change the gain without opening the door. | (a) leave them on the control board inside the box; (b) put them on the enclosure's right wall beside the key switch, with short leads inside the box like the key switch's; (c) a sealed selector and light on the deck's front edge, with a lead into the box through a gland. | (b): the rider reaches them at a stop with the key switch, no lead crosses the door's hinge, and two more panel holes cost little (about $3). Proposed, awaiting Amish. | The enclosure's right wall (two more holes), the control board's leads, the appearance model and renders | Review note 2026-10-02 |

## To confirm when parts are bought

| # | What to confirm | Why it matters | Source |
| --- | --- | --- | --- |
| 1 | The S-type load cell fits the 56.3 mm housing bore: body no more than 54 mm across its diagonal (about 51 x 13 x 61 mm assumed), M10 threads at both ends | The cell lives inside the coupler housing | CGM-DDR-003, P1 |
| 2 | The hub motor: 100 mm spacing, 10 mm axle flats, disc mount, shell no more than 156 mm across within 16 mm of the disc-side locknut, cable exit on the non-disc side, torque arm in the kit | Sets the slot width, the caliper clearance and the cable route | CGM-DDR-003, P9, P10 |
| 3 | The caliper's post-mount adapter for a 180 mm rotor: hole spacing on the dropout tab | The tab's two holes are drilled to suit | CGM-DDR-003, P9 |
| 4 | The hitch's arm is 32 mm or less and takes the 6 mm locking pin; the hitch fits the bicycle's axle type | The arm goes 60 mm into the drawbar's 33 mm bore | CGM-DDR-003, P7; R7 |
| 5 | The preload spring: about 30 N installed, free length about 96 mm, OD 40 mm or less, solid length under 40 mm | It sets the brake's onset and must not go solid within the 50 mm stroke | CGM-CAL-001, F3 |
| 6 | Motor constants (winding, resistance, thermal) from the datasheet | They decide whether R3 holds (decided under CGM-DDR-002; part selection is TRL 4) | CGM-DDR-002, D12 |
| 7 | Rivet nuts rated for 1.5 mm wall box section | They carry the deck, the enclosure and the lights | CGM-DDR-003, P8, P11 |
| 8 | The key switch fits a 19 mm panel hole, and the 3-pin charge socket fits a 24 mm hole with its two M3 flange screws 24 mm apart and mates with the charger's plug; both sealed to IP65 with the cap closed | The two holes in the enclosure's right wall are cut to suit | CGM-DDR-003, A2; R11 |

## Value engineering

Value-engineering target: USD 1,000 (a hypothetical control target, not a limit). Estimated cost of the constructable design: USD 1,004 (USD 4 over the target).

Main cost drivers (CGM-CAL-001, I1): the battery pack (line 11, $180), the hub motor wheel (line 7, $160), the chassis frame (line 1, $95), the deck and side boards (line 2, $77) and the overrun brake coupler (line 6, $58). The parts added to make the design buildable added $18 (CGM-DDR-003), and the decisions of 2026-10-02 added $7: the charge socket with its cap on the enclosure's right wall (about $4) and the drawbar reflector (about $3).

Savings worth trying:

- Salvaged 20 in wheels and brakes and a lighter enclosure, which the TRL 3 review estimated could bring the parts to about $900.
- Straps or mesh in place of the plywood side boards (the trailer weighs 43.5 kg without the plywood side boards, CGM-DDR-003 A1 and CGM-CAL-001 A3, plus the straps or mesh), the fallback if the weighed prototype is over the 47 kg cap of R8 (CGM-DDR-003, A1).
- A SwapCell receiver in the fleet variant, which would price the shared pack once and leave it out of this kit (CGM-DDR-001, D2).

## Decisions made

| Date | Decision | Decided by | Record |
| --- | --- | --- | --- |
| 2026-09-25 | TRL 2 review items D1 to D10: cost cuts then a $1,000 budget, 36 V LiFePO4 384 Wh pack, steel frame, one hub motor in the left wheel, proportional assist G = 2 to 6, overrun mechanical brake plus assist cut, pitch reworded, drawbar force sensing, 20 in wheels with the hitch on the left axle end, handcart mode out of scope | Amish: "proceed with all of your recommendations across all batches. Make sure we don't proceed to TRL 4 on any of them." | CGM-DDR-001 |
| 2026-09-25 | TRL 3 items D11 to D14: R8 relaxed to 45 kg with straps or mesh as a later weight option, thermal derating and a use limit for long climbs, 180 mm rotors with metallic pads, gain range kept at 2 to 6 | Amish: "i accept all your recommendations, go with them across all repos." | CGM-DDR-002 |
| 2026-09-30 | Make the design physically buildable while drawing the build plan; outstanding decisions go in this register, not the plan | Amish: "If you are realising that the design cannot be built as per concept - fix the design assumptions to match and be physically feasible as you draw the illustrations." | CGM-DDR-003 (Draft; Table 3 and then Table 1 accepted on 2026-10-02, below) |
| 2026-10-02 | R8 set to 47 kg as a hard cap for the first prototype only, not a new target; the trailer is weighed at TRL 4, and straps or mesh side boards are the fallback if it weighs more than 47 kg | Amish: "i approve your recommendations for all 555 open decisions." | CGM-DDR-003, A1 |
| 2026-10-02 | Key switch and charge port on the enclosure's right wall near the front, so no lead flexes across the door hinge | Amish: "i approve your recommendations for all 555 open decisions." | CGM-DDR-003, A2 |
| 2026-10-02 | Coupler damping: friction washers on the lever pivot for the prototype; a rough-road chatter check is a pass condition at TRL 4, and the small hydraulic damper is fitted if the brake chatters or grabs | Amish: "i approve your recommendations for all 555 open decisions." | CGM-DDR-003, A3 |
| 2026-10-02 | Appearance model and photoreal renders to be updated to the constructable design on Amish's Mac before the repo is made public | Amish: "i approve your recommendations for all 555 open decisions." | CGM-DDR-003, A4 |
| 2026-10-02 | Keep the BOM's paint and sealed plywood for the prototype; the powder coat, faced boards, badges, tie-down tracks and gaiter are labeled as finished-product styling in the renders; the drawbar reflector is to be added to the BOM | Amish: "i approve your recommendations for all 555 open decisions." | Review note 2026-09-26, item 4 |
| 2026-10-02 | Hero render composition accepted as it is; a kit close-up camera only if a load cell detail shot is wanted | Amish: "i approve your recommendations for all 555 open decisions." | Review note 2026-09-26, item 5 |
| 2026-10-02 | First users chosen by one rule: a group moving 50 to 150 kg loads on short, repeated urban trips by bicycle or hand cart on paved, hilly routes. First candidate type to approach: a community food bank's local delivery or pantry runs; market traders are the second choice | Amish: "i approve your recommendations for all 555 open decisions." | CGM-DDR-001, O1 |
| 2026-10-02 | Until a written legal check exists for the first partner's country, the trailer is for private ground only; the EU pedal-assist limits (250 W, assist only under pull, cut at 25 km/h, no throttle) stay the design rule as the strictest common case | Amish: "i approve your recommendations for all 555 open decisions." | CGM-DDR-001, O2 |
| 2026-10-02 | Design for construction accepted: the changes P1 to P15 in Table 1, as made | Amish: "APPROVED: Design-for-construction changes in 10 repos (CityTwin, CoolShade, PalletPilot, Heliolite, PotholeLog, EarthPress, ReadyKit, CellCheck, CargoMule and ThermaCart)" | [CGM-DDR-003](decisions/0003-design-for-construction.md), Table 1 |

The review note of 2026-09-26 also proposed a closed enclosure with a bottom or front access panel (item 1), controls on the enclosure's front face (item 2) and a clear guard over the load cell with an enclosure window (item 3). Items 1 and 3 are closed: CGM-DDR-003 overtook them (the enclosure has a front door, P8, and the load cell sits inside the coupler housing, P1). Item 2 is closed by the 2026-10-02 decision on CGM-DDR-003, A2.

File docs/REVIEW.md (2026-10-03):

# Review note: CargoMule

## Session 2026-10-02: approved follow-ups carried out

Amish, 2026-10-02: "497 follow-up actions that need CAD, drawing, picture, BOM or calculation work ... APPROVED CHANGES, COMPLETE THESE" and "Photoreal renders are out of date in most repos ... COMPLETE THESE". The follow-up actions listed in the session "open decisions decided by Amish" below were carried into the design. trl stays 3; nothing was built or tested.

### Follow-ups

| # | Follow-up | Status | What changed |
| --- | --- | --- | --- |
| 1 | R8 target in `docs/04-calcs/sizing.py` to the 47 kg prototype cap | Done | Line [A3] and the status table now use the 47 kg cap; a rerun reproduces CGM-CAL-001 (v0.6) |
| 2 | Key switch and charge port holes in the enclosure's right wall near the front, harness route, constructability checks | Done | `cad/src/model.py`: a 19 mm key switch hole 80 mm and a 24 mm charge socket hole 145 mm behind the front face, 95 mm up, with the socket's two flange screw holes; the switch and socket as parts; their leads inside the box (charge lead to the pack's side, key switch lead over the controller to the board), none across the door's hinge. 13 checks added (86 in all, all pass), including "no lead across the door hinge" (77 mm clear of the door). STEP and STL re-exported |
| 3 | Regenerate the enclosure making sketch and CGM-DWG-001 | Done | CGM-DWG-110 Rev P2 (holes and note); CGM-DWG-001 Rev P5 (note line with the hole positions) |
| 4 | Build plan pictures of the enclosure and harness steps; drilling of the two holes in the enclosure text | Done | Overview, steps 10 to 16 regenerated (the switch and socket are on the far side in the step 11 view, which is seen from below on the left; the making sketch shows the holes); CGM-BLD-001 v0.4: making step 6 of the enclosure (the two holes), its fit and check, step 11 (fitting the switch and socket and running their leads), step 15 (plugging in and unplugging the charge lead), bought-parts list, first checks and safety stop S7 |
| 5 | Chatter check in the TRL 4 test plan | Not done, by rule | A test plan is TRL 4 work and the portfolio is capped at TRL 3 (CLAUDE.md section 1). The decision stays recorded in CGM-DEC-001; write the check into the test plan when TRL 4 is opened |
| 6 | `cad/src/product_model.py` to the constructable design; key switch and charge port on the right wall; renders, card and social preview on Amish's Mac | Model done; renders pending on the Mac | Appearance model rebuilt from `build_components()`: coupler housing with the load cell, cage, rod and bushings inside, end cap, window cover, brake lever, model brake cables and splitter, calipers on the dropout tabs, torque arm; closed enclosure with the bottom-hinged door and lock, rear vent, glands, and the key switch and charge socket on the right wall; model pack, controller and board positions and leads. Removed: the clear load cell guard, the damper housing, the enclosure window and seam, the front-face controls. Render scenes exported (below). `media/render-*.png`, `media/card.png` and `media/social-preview.png` are still the old ones until they are rendered on the Mac |
| 7 | Drawbar reflector in `bom/bom.csv` and `bom/bom-notes.md`; rerun cost and mass | Done | Line 15: amber drawbar reflector on two hose clips, about $3 and 0.05 kg; also modelled on the drawbar's outer face (2 checks). Line 14 names the key switch and a 3-pin charge socket with cap (about $4 added); line 10 names the two holes |
| 8 | Captions that label powder coat, faced boards, badges, tie-down tracks and gaiter as finished-product styling | Done in the scene notes | Each RENDER_VIEWS note says so; the captions are applied with the renders on the Mac. Caption layout was tried on a blank 1,600 x 1,200 image and fits |

### Key results (CGM-CAL-001 v0.6)

- Empty mass 46.3 kg (was 46.2 kg), 0.7 kg under the 47 kg prototype cap: R8 met on paper, unchanged status. Without side boards 43.5 kg. Small knock-on changes: loaded 196.3 kg, motor asked 136.5 N, wheel reaction 1,853 N, ultimate hitch case 1,926 N; no other figure moved.
- Value-engineering target: USD 1,000. Estimated cost of the constructable design: USD 1,004 (USD 4 over the target). **R12 status changed** from "within the value-engineering target ($3 under)" to "over the value-engineering target by $4". `budget_usd` unchanged.
- Requirement counts: 8 met (6 on paper, 2 by design), 3 at risk (R3, R6, R7), R12 over its value-engineering target, 2 not verifiable at TRL 3.

### Documents changed

- `cad/src/model.py`, `cad/step/*.step`, `cad/stl/*.stl`
- `bom/bom.csv`, `bom/bom-notes.md`
- `docs/04-calcs/sizing.py`; `docs/04-calcs/01-sizing.md` (CGM-CAL-001 v0.6)
- `docs/03-requirements.md` (CGM-REQ-001 v0.8), `docs/02-concept.md` (CGM-PRC-001 v0.8), `docs/05-build-plan.md` (CGM-BLD-001 v0.4), `docs/06-design-decisions.md` (CGM-DEC-001 v0.5), `README.md`
- `cad/src/sheets.py`, `cad/drawings/CGM-DWG-001` Rev P5; `cad/src/build_plan_media.py`, `cad/drawings/CGM-DWG-110` Rev P2, `docs/05-build-plan/overview.png`, `step-10.png` to `step-16.png`
- `cad/src/concept_media.py` and `media/` concept set (hero, blueprint, cutaway, exploded, flow, model.glb)
- `cad/src/product_model.py`; render scenes in `/home/claude/renders/cargomule/` (hero, exploded, detail: one .npz and .json each, plus `cargomule__jobs.json`)
- PDFs regenerated

### Proposed, awaiting Amish

- **Gain selector and status light position** (register item 9, new). The 2026-09-26 renders had them on the front face, now the door; the BOM puts them on the control board inside the locked box. Recommendation: put them on the right wall beside the key switch (about $3 more). Until decided, the appearance model shows neither outside the box.
- **Appearance deviations** (STANDARDS section 12): the drawbar gaiter, powder coat, faced side boards with hand slots, trim, name badges and deck tie-down tracks are finished-product styling decided on 2026-10-02 and captioned as such; the hitch, hub motor shell, slotted rotors, rider and bicycle are drawn for realism and are not in `model.py`; the enclosure is drawn with rounded vertical corners and rivets. Recommendation: accept as styling.

### Points found

- The 2026-10-02 key switch decision names a "charge port"; the BOM did not price one. A 3-pin charge socket with a cap was added at about $4, which with the reflector puts the estimate $4 over the target. A cheaper fit (an inline keyed connector on a short pigtail through a gland) would save about $3 if wanted.

### Cross-repo actions

None for this repo.

### Safety

The charge socket brings charging to the trailer's side: safety stop S7 now says to charge only through it, with the key switch off. Leads stay inside the box and do not flex at the door. No change to the safety case.

### Recommended next step

Render `media/render-hero.png`, `render-exploded.png` and `render-detail.png` from the exported scenes on Amish's Mac, then `python .kit/cards.py .`. Amish decides register item 9. TRL 4 remains on hold.

## Session 2026-10-02: design-for-construction changes accepted

Amish, 2026-10-02: "APPROVED: Design-for-construction changes in 10 repos (CityTwin, CoolShade, PalletPilot, Heliolite, PotholeLog, EarthPress, ReadyKit, CellCheck, CargoMule and ThermaCart)". This accepts the design-for-construction changes P1 to P15 in Table 1 of CGM-DDR-003, which were left open for his review when the open decisions were decided earlier the same day (session below). No other item is decided by it. trl stays 3; no build or test work was done, and the model, BOM quantities and prices, calculations and pictures are unchanged.

### Documents changed

- `docs/decisions/0003-design-for-construction.md` (CGM-DDR-003 v0.4, status Draft): status line now "accepted" with Amish's words.
- `docs/06-design-decisions.md` (CGM-DEC-001 v0.4): Decisions made row added, dated 2026-10-02.
- `docs/05-build-plan.md` (CGM-BLD-001 v0.3): section 2 says the Table 1 changes are accepted.
- `README.md` and `bom/bom-notes.md` (not controlled documents): CGM-DDR-003 no longer described as open for review.
- PDFs regenerated.

### Recommended next step

No change: the follow-up actions of the session below stand. TRL 4 remains on hold by Amish's instruction.

## Session 2026-10-02: open decisions decided by Amish

Amish wrote on 2026-10-02: "i approve your recommendations for all 555 open decisions." Every open decision in this repo's register was decided as recommended and moved to "Decisions made" in `docs/06-design-decisions.md`, dated 2026-10-02.

### Decisions recorded

8 decisions recorded (register items 1 to 8). The register's "Open decisions" section now reads: "None. All open decisions were decided on 2026-10-02."

### Documents changed

- `docs/06-design-decisions.md` v0.3
- `docs/decisions/0003-design-for-construction.md` v0.3
- `docs/decisions/0001-trl2-review-decisions.md` v0.3
- `docs/decisions/0002-recommendations-accepted.md` v0.2
- `docs/03-requirements.md` v0.7
- `docs/04-calcs/01-sizing.md` v0.5
- `docs/02-concept.md` v0.7
- `docs/01-problem.md` v0.6
- `docs/05-build-plan.md` v0.2
- `README.md` (safety note; not a controlled document)

PDFs re-rendered with `python3 .kit/render.py`. The CAD model, BOM quantities and prices, and pictures were not changed.

### Follow-up actions to carry approved decisions into the design

1. Decision 1 (calculations): Change the R8 target in `docs/04-calcs/sizing.py` (line A3 and the status table) from 45 kg to the 47 kg prototype cap so that a rerun reproduces CGM-CAL-001 v0.5, which was edited by hand.
2. Decision 2 (model): Add the key switch and charge port holes to the enclosure's right wall near the front in `cad/src/model.py`, with the harness route to them, and rerun the constructability checks.
3. Decision 2 (drawings): Regenerate the enclosure making sketch and CGM-DWG-001 with the key switch and charge port holes.
4. Decision 2 (build plan pictures and renders): Regenerate the build plan pictures of the enclosure and harness steps and add the drilling of the two holes to the enclosure step text of CGM-BLD-001.
5. Decision 3 (documents): When TRL 4 is opened, write the rough-road chatter check of the coupler into the test plan as a pass condition, with fitting the small hydraulic damper as the response to chatter or grabbing.
6. Decision 4 (build plan pictures and renders): Update `cad/src/product_model.py` to the constructable design and regenerate `media/render-*.png`, `media/card.png` and `media/social-preview.png` on Amish's Mac before the repo is made public; show the key switch and charge port on the enclosure's right wall.
7. Decision 5 (BOM): Add a drawbar reflector to `bom/bom.csv` and `bom/bom-notes.md` (price and mass), then rerun the cost and mass lines of CGM-CAL-001.
8. Decision 5 (build plan pictures and renders): Caption the renders so that the powder coat, faced boards, badges, tie-down tracks and gaiter read as finished-product styling, not the prototype's paint and plywood.

### Points found in the review

- Item 1, option (b) gives about 43.9 kg without plywood boards, while R8's status row in CGM-REQ-001 v0.5 gives 43.4 kg without side boards; the two figures should be reconciled (the difference may be the straps or mesh).
- REVIEW.md 2026-09-26 appearance items 1 to 3 (closed enclosure, controls on the front face, load cell guard and enclosure window) are not in the register. Items 1 and 3 appear superseded by CGM-DDR-003 (P1 and P8) and item 2 is replaced by register item 2; they should be closed explicitly.
- R8 has been relaxed from 35 to 40 to 45 kg and is now proposed at 47 kg; the requirement may need restating as a prototype cap with a separate product target.
- Descent speed limit: CGM-CAL-001 says a descent speed limit is still needed (225 K rotor rise on 10 % at 25 km/h), but it is not in the open decisions register.
- CGM-DDR-003 Table 1 (the changes made for construction) was not itself an open decision in the register, so only Table 3 was accepted in this session. Amish accepted Table 1 later on 2026-10-02 (see the session above); the record stays Draft.
- Flag 2 above is now handled in the register: the 2026-09-26 appearance items 1 to 3 are recorded as closed under "Decisions made".

TRL 4 remains on hold by Amish's instruction.

## Session 2026-10-01: kit 1.7.0, design for construction and prototype build plan

Following Amish's 2026-09-30 instruction ("If you are realising that the design cannot be built as per concept - fix the design assumptions to match and be physically feasible as you draw the illustrations") and the build plan format he approved for FieldNode, with outstanding decisions kept out of the plan and in a separate register.

### What was done

- Kit 1.7.0 installed (`.kit/`, `.claude/commands/`); `CLAUDE.md` replaced by `.kit/CLAUDE.md`.
- Constructability review of the TRL 3 model with build123d (overlaps, contacts, fixings, assembly order, process). `cad/src/model.py` rewritten as a constructable model with `build_components()` and 73 checks (`python cad/src/model.py --check`), all passing.
- `docs/decisions/0003-design-for-construction.md` (CGM-DDR-003 v0.1, Draft): every change, made under Amish's 2026-09-30 instruction to make the design physically buildable; open for his review.
- `cad/src/build_plan_media.py`: overview, eleven making sketches (`cad/drawings/CGM-DWG-101` to `111`), ten joint close-ups and sixteen assembly step pictures in `docs/05-build-plan/`.
- `docs/05-build-plan.md` (CGM-BLD-001 v0.1) and `docs/06-design-decisions.md` (CGM-DEC-001 v0.1).
- Calculations rerun: `docs/04-calcs/sizing.py` now takes made-part masses from the model's volumes; CGM-CAL-001 v0.3, CGM-REQ-001 v0.5, CGM-PRC-001 v0.5. `bom/bom.csv` and `bom/bom-notes.md` updated ($997).
- CGM-DWG-001 Rev P4 regenerated; `cad/src/sheets.py` now repairs collapsed elliptical arcs in the projected views, which drew a stray line across the sheet. STEP and STL re-exported; concept media regenerated.
- `project.yaml`: `design_state: constructable`; DDR-003, the build plan, the register, the overview picture and the media script added to `trl_evidence`. README: links line and a "Building the prototype" section.

### Design changes made for construction (CGM-DDR-003)

1. Load cell moved inside a coupler housing welded into the frame nose; the drawbar slides in two bushings that carry its bending and tongue load; pull goes through a rod end, clevis pin, cell and pull rod to a spring cage's bulkhead.
2. Overload stop and anti-rotation: a slotted fork on the housing with a closed front end; an M12 pin through the drawbar rests 0.5 mm behind it.
3. Assembly order: spring, rod and cell go in from the rear as a cartridge under a bolted end cap; the clevis pin goes in through a 70 x 24 mm side window with a rubber cover.
4. Brake lever: 20 x 6 mm lever, 7.7 to 1, on a bolt between cheeks under the housing; friction washers in place of a hydraulic damper; one cable to a splitter, then one to each caliper.
5. Drawbar: one tube with three 115 mm radius bends; straight rear part from 700 mm; welded end plug.
6. Nose: nose bars fishmouthed onto the coupler housing (the concept's solid ball removed).
7. Hitch arm 32 mm into the drawbar's 33 mm bore with a locking pin.
8. Enclosure: 350 mm long, bolted up into the crossmembers at 1,600 and 1,920 mm, front door hinged at the bottom with a lock; the pack slides out forward.
9. Calipers on post-mount adapters on rearward tabs of the inner dropout plates, clear of the motor shell.
10. Axle slots in all four dropouts; a torque arm on the left inner dropout.
11. Deck on 16 M6 bolts into rivet nuts; boards held by aluminium corner pieces and brackets with wing nuts.
12. Flag pole in two clips; rear lights bolted to the rear rail.
13. Parking stand pivoted in a clevis under the housing.
14. Harness rerouted (motor cable along the left arch frame; cell cable out of the end cap; light cables under the deck).
15. Rails and tubes modelled hollow with capped ends.

### Key results (CGM-CAL-001 v0.3)

- **R8 not met:** 46.2 kg against 45 kg (43.2 kg before); the coupler, fixings and fittings add 3.0 kg. Proposed, awaiting Amish (register item 1).
- R3 still at risk: 38.7 N felt (was 36.6 N, target 40 N); winding 96 °C. R6 still at risk: 93 N dry, 111 N wet. R7 at risk.
- Range 24.5 km; hitch load 7.5 kg (window 32 mm ahead to 57 mm behind the deck centre); drawbar factor 4.3 at the front bushing; width 960 mm (972 mm over the motor cable); BOM $997 against $1,000.

### Proposed, awaiting Amish

See `docs/06-design-decisions.md`: R8 response (recommend relaxing to 47 kg for the prototype), key switch and charge port position (recommend the enclosure's right wall), coupler damping (recommend friction washers for the prototype), updating the appearance model and renders, render styling and composition (from 2026-09-26), and O1 and O2 (no recommendation).

### Stale media (made on Amish's Mac, not regenerated here)

`media/render-hero.png`, `media/render-exploded.png`, `media/render-detail.png`, `media/card.png` and `media/social-preview.png` show the concept's coupler, load cell guard, top-opening enclosure with a window and harness, so they are stale. `cad/src/product_model.py` still builds from `build_parts()` (same group names) but its appearance parts follow the concept.

### Safety

The coupler adds pinch points at the fork slot, the side window and the lever cheeks; the build plan has safety stops for welding, tube bending, the battery, first motor power, hitching and the first loaded roll (private ground only). The overload pin now protects the load cell. No change to the safety case.

### Problems and notes

- `.kit/drawing.py` `project_views` still fails on this model's degenerate edges; the repo keeps its own `safe_project_views` in `cad/src/sheets.py`, now also repairing collapsed arcs. A kit fix is suggested.
- In `.kit/build_views.py` sketches, the "Front view" label is the side elevation for this trailer (kit naming), as noted on 2026-09-25.

### Recommended next step

Amish reviews CGM-DDR-003 and decides register items 1 to 4. TRL 4 (building to this plan) stays on hold.

## Session 2026-09-26: sources strengthened

Amish asked on 2026-09-26 to "fix the weaker sources." Links in the README sections Concept rationale to What sparked the idea were checked; the three uncited country rows were rewritten or replaced with cited rows, and trade-press price sources were replaced with the manufacturer's page.

| Item | Old source | New source |
| --- | --- | --- |
| Netherlands row | None (uncited claim about cargo-bike habit and bridges) | KiM Netherlands Institute for Transport Policy Analysis, *Cycling Facts 2023* (1.3 bicycles per person, 28 % of journeys, cargo bikes 2 % of new e-bike sales); row rewritten to match |
| Kenya and East Africa row | None | Replaced by Uganda and East Africa, citing the World Bank case study by Malmberg Calvo (1994), SSATP Working Paper 12 (bicycle traders with about 100 kg loads pushing up hills) |
| Colombia and Andean cities row | None | Replaced by Colombia (Bogotá), citing the Secretaría Distrital de Movilidad's 2023 mobility survey release (886,655 daily bicycle trips, 7 %) |
| United States row, cargo e-bike price | The Inertia (review) and Notebookcheck (trade press) | Rad Power Bikes RadWagon 5 product page ($2,399); the unverified $4,999 Tern figure removed |
| India row | Street Vendors Act only; uncited claim about daily hand-cart and bicycle use | Uncited clause removed; row now states only what the Act supports |
| CGM-PRB-001 cost of alternatives | The Inertia and Notebookcheck | Rad Power Bikes product page; CGM-PRB-001 v0.3 to v0.4 |

Kept and re-checked: European Environment Agency transport indicator, WHO ambient air quality fact sheet, and the 2013 CycleLogistics baseline study (Reiter and Wrighton, FGM-AMOR, EU IEE grant IEE/10/277), which is the primary report (hosted by cargobike.jetzt). Kept but not re-fetched this session: Carla Cargo's own eCARLA page, India Code (Street Vendors Act, 2014) and Cornell LII (15 U.S.C. 2085). No budget change.

## Session 2026-09-25: recommendations accepted

Amish wrote on 2026-09-25: "i accept all your recommendations, go with them across all repos." Every open item with a recommendation is now decided by Amish, 2026-09-25: go with recommendation, and recorded in `docs/decisions/0002-recommendations-accepted.md` (CGM-DDR-002 v0.1). TRL stays at 3; TRL 4 remains on hold.

### Decisions applied and what changed

| # | Decision | Before | After |
| --- | --- | --- | --- |
| D11 | R8 relaxed to 45 kg for the first prototype; straps or mesh side boards kept as a later weight option | R8 40 kg; 43.1 kg, not met | R8 45 kg; 43.2 kg, met on paper |
| D12 | Keep the 250 W motor, add thermal derating and state a use limit of about 300 m of continuous 8 % climbing; confirm motor constants from a datasheet | R3 at risk; derating only suggested | R3 restated with the derating rule and use limit; derating starts after about 336 m [C10]; felt pull rises toward about 114 N on an endless climb; datasheet check on hold (TRL 4 part selection); R3 still at risk |
| D13 | 180 mm rotors with metallic pads | 160 mm rotors; push 100 N dry, 119 N wet; rotor rise 166 K on 8 %; BOM $969 | 180 mm rotors; push 92 N dry, 110 N wet; rotor rise 129 K; BOM $979; R6 still at risk in the wet |
| D14 | Keep G = 2 to 6 on paper; set the top gain once hitch joint stiffness is known | Open | Decided; the stiffness measurement is TRL 4, on hold; no design change |

Files changed:

- `cad/src/model.py`: `rotor_d` 160 to 180 mm; `cad/step/` and `cad/stl/` re-exported.
- `cad/src/sheets.py` and `cad/drawings/CGM-DWG-001.svg`, `.pdf`, `.png`: Rev P1 to P2 (rotor note and revision row).
- `bom/bom.csv` item 9: $20 to $25 per wheel, 180 mm rotors, metallic pads; `bom/bom-notes.md` updated. Total $969 to $979; `budget_usd` stays $1,000.
- `docs/04-calcs/sizing.py` and `01-sizing.md`: CGM-CAL-001 v0.1 to v0.2 (rotor mass and area scaled, lever kept at 7.7:1, brake gain 6.9 to 7.8, new [C10] derating check, R8 at 45 kg, results table).
- CGM-REQ-001 v0.3 to v0.4 (R8 45 kg, R3 restated); CGM-PRC-001 v0.3 to v0.4; CGM-DDR-001 v0.1 to v0.2 (R8 note points to DDR-002); new CGM-DDR-002 v0.1. CGM-PRB-001 unchanged at v0.3.
- `project.yaml`: DDR-002 added to `trl_evidence`; budget, pitch and problem unchanged; `trl: 3`, `trl_target: 3`.
- `README.md`: new sections Concept rationale, Burning platform, Where it could be used and What sparked the idea (the 2013 CycleLogistics baseline study); Concept paragraph and key components updated.
- `cad/src/concept_media.py` key figures ($979, 180 mm brakes); all media, drawings and `docs/pdf/` regenerated with the designmolecule.com footer. Temporary `media/_views*` folders deleted.

### Requirement status (CGM-CAL-001 v0.2)

Nine met (seven on paper, two by design), three at risk, none not met, two not verifiable at TRL 3.

| ID | Status | Value against target |
| --- | --- | --- |
| **R3 hills** | **At risk** | 36.6 N felt (40 N); winding about 95 °C against 100 °C after 300 m on assumed constants; derating beyond about 336 m |
| **R6 braking** | **At risk** | 92 N push dry, about 110 N wet (100 N); cut about 60 ms |
| **R7 hitch fit** | **At risk** | Axle stresses pass; thru-axle threads vary; nutted axles need adapters |
| R1, R2, R4, R8, R9, R10, R12 | Met on paper | 0.84 m², factor 1.6; 24.9 km; 6.2 to 6.6 N; 43.2 kg (45 kg); 960 mm, 2.52 m; 7.8 kg; $979 |
| R5, R14 | Met by design | 250 W, tension only, 25 km/h, no throttle; flag top 1,570 mm |
| R11, R13 | Not verifiable at TRL 3 | Datasheet items; 60 ms fault path on paper |

### Still awaiting Amish

1. **O1, first users and region** for co-design. No recommendation; Proposed, awaiting Amish.
2. **O2, road legality** of a motorized bicycle trailer in the first target country. No recommendation; Proposed, awaiting Amish.

### Cross-repo actions

None. The four decisions affect CargoMule only. (The SwapCell fleet variant under CGM-DDR-001, D2 is unchanged and not designed at TRL 3.)

### Safety

The safety sections stay in the README, precis and calculation note. New points: the motor derating means assist fades near the top of long climbs, so riders must be warned of the use limit; wet braking still gives about 110 N of push; descents still need a speed limit.

### TRL 4

TRL 4 remains on hold by Amish's instruction. Decided but on hold: the motor datasheet and bench thermal check (D12) and the hitch joint stiffness measurement that settles the top gain setting (D14). No tests, build procedures, purchasing lists, firmware or PCB files were created.

## Session 2026-09-25: TRL 3

Amish approved all recommendations from the TRL 2 review on 2026-09-25 ("proceed with all of your recommendations across all batches. Make sure we don't proceed to TRL 4 on any of them."). This session took CargoMule to TRL 3 and stopped there.

### What was done

- `docs/decisions/0001-trl2-review-decisions.md` (CGM-DDR-001 v0.1): ten decided items (D1 to D10) and two open items (O1, O2).
- `docs/04-calcs/01-sizing.md` (CGM-CAL-001 v0.1) and `docs/04-calcs/sizing.py`: mass and balance, assist forces, motor and heating, loop stability, energy, braking, structure, geometry and cost, with a results table for R1 to R14. The script imports the model's `PARAMS` and reads the BOM and budget, and every quoted number carries the tag of the line that prints it.
- `cad/src/model.py`: parametric build123d model (frame with wheel arch frames and dropouts for 100 mm hubs, 12 mm deck and side boards, offset drawbar, hitch, load cell, overrun coupler, wheels, brakes, enclosure, pack, controller, board, harness, lights, stand). Exports `cad/step/` and `cad/stl/`: `cargomule-assembly`, `frame`, `drawbar-assembly`, `deck`, `enclosure`.
- `cad/src/sheets.py` and `cad/drawings/CGM-DWG-001.svg`, `.pdf`, `.png`: general arrangement, Rev P1, 1:20, "CONCEPT, NOT FOR FABRICATION" and "PRELIMINARY, NOT FOR FABRICATION". The concept sheet stays CGM-DWG-010.
- `bom/bom.csv` and `bom/bom-notes.md`: 18 lines, every line priced with a supplier type; total $969 against the $1,000 budget.
- `cad/src/concept_media.py` now builds from the model; all media refreshed (`hero.png`, `concept-blueprint.png`, `.pdf`, `.svg`, `exploded.png`, `cutaway.png`, `flow.png`, `model.glb`, `viewer.html`). Temporary `media/_views*` folders deleted.
- CGM-PRB-001, CGM-PRC-001 and CGM-REQ-001 revised to v0.3; `project.yaml` (TRL 3, budget $1,000, pitch) and `README.md` updated; PDFs rebuilt in `docs/pdf/`.

### Requirements (CGM-CAL-001, Table 5)

Eight met (six on paper, two by design), three at risk, one not met, two not verifiable at TRL 3.

| ID | Status | Value against target |
| --- | --- | --- |
| **R8 mass** | **Not met** | 43.1 kg against 40 kg (relaxed); 40.3 kg without side boards |
| **R3 hills** | **At risk** | 36.6 N felt (40 N) met; winding about 95 °C against 100 °C after 300 m on assumed motor constants; 174 °C after 1,000 m |
| **R6 braking** | **At risk** | 100 N push dry by sizing, about 120 N with wet pads; rotor rise 166 to 284 K on long descents; cut about 60 ms |
| **R7 hitch fit** | **At risk** | Axle stresses pass; thru-axles need a hitch axle per thread and length; nutted axles need adapters |
| R1, R2, R4, R9, R10, R12 | Met on paper | 0.84 m², least factor 1.6; 25.0 km; 6.2 to 6.6 N and stable; 960 mm, 2.52 m; 7.8 kg; $969 |
| R5, R14 | Met by design | 250 W, tension only, 25 km/h, no throttle; flag top 1,570 mm |
| R11, R13 | Not verifiable at TRL 3 | Datasheet items; 60 ms fault path on paper |

### Key results and changes from TRL 2

- **The TRL 2 assist filter would oscillate.** A first-order 2 Hz filter goes unstable above G = 0.5 at the softest drawbar stiffness considered. A second-order 0.7 Hz filter is stable for G = 2 to 6 (gain margin 2.9 at G = 4, 1.9 at G = 6), at the cost of about 0.47 s of assist lag. The compression cut acts on the raw signal.
- **A straight drawbar hits the bike's tyre after about 10° of yaw.** The drawbar now runs 360 mm out to the left, allowing 55.5° (about 1.3 m turn radius), and was upsized to 38 x 2.5 mm S355 for the offset.
- **Motor current.** The climb needs 24.1 A phase and 14.9 A from the pack; a controller with a lower limit would leave the rider feeling 57 to 72 N. The controller spec now states 15 A pack and 30 A phase.
- **Mass rose from about 38 kg to 43.1 kg:** realistic plywood mass, the wheel arch frames that the two-sided hub dropouts need, and the offset drawbar. A 9 mm deck failed a point-load check (15 MPa), so the deck stays 12 mm.
- **Hitch load** is 7.8 kg with the axle moved 30 mm forward, but the loading window for 3 to 10 kg is only 90 mm long.
- **Range** 25.0 km (13.9 Wh/km); mains 160 Wh per trip; braking needs 479 N from the trailer.
- **Cost** $969 after the D1 cuts (minus $50) and TRL 3 additions (plus $54).

### Decisions recorded (CGM-DDR-001)

All decided by Amish, 2026-09-25: go with recommendation. D1 budget: cost cuts, then `budget_usd` raised to $1,000 (R12 redefined). D2 battery: 36 V LiFePO4, 384 Wh; SwapCell as a later fleet variant (it would build to SwapCell interface v0.3, with the shared pack priced once outside this kit). D3 steel frame, R8 relaxed to 40 kg. D4 one hub motor in the left wheel. D5 proportional assist, selectable G = 2 to 6, default 4. D6 overrun mechanical brake plus assist cut. D7 pitch reworded to "fits most bicycles" and "a fraction of the load" (applied to `project.yaml` and `README.md`). D8 drawbar force sensing. D9 20 in wheels, hitch on the left axle end. D10 handcart mode out of scope.

### Still awaiting Amish

1. **O1, first users and region** for co-design (market traders, a trades cooperative or a community food bank). No recommendation; partners to be picked per area later.
2. **O2, road legality** of a motorized bicycle trailer in the first target country. No recommendation was made; it stays open.
3. **New: response to the R8 miss (43.1 kg).** Options: (a) relax R8 to 45 kg for the first prototype; (b) replace the plywood side boards with straps or mesh (about 40.3 kg, still just over); (c) an aluminium frame (about 5 kg lighter, about $60 more, TIG welding; reopens D3). Recommendation: (a), with (b) as a later weight option. Proposed, awaiting Amish.
4. **New: long climbs (R3).** Options: (a) keep the 250 W motor, add thermal derating and state a use limit of about 300 m of continuous 8 % climbing; (b) a larger motor, which would break the 250 W pedal-assist limit (R5). Recommendation: (a), and confirm the motor constants from a datasheet. Proposed, awaiting Amish.
5. **New: wet braking and descents (R6).** Options: (a) accept about 120 N of wet push; (b) 180 mm rotors with metallic pads (about $10 more, raises brake gain and heat capacity); (c) a higher coupler lever ratio (more stroke). Recommendation: (b). Proposed, awaiting Amish.
6. **New: highest gain setting.** G = 6 has a 5.8 dB margin at the softest stiffness, just under 6 dB. Options: keep 2 to 6, or cap at 5. Recommendation: keep 2 to 6 on paper and decide once the hitch joint stiffness is known. Proposed, awaiting Amish.

Update: items 3 to 6 were decided by Amish, 2026-09-25: go with recommendation (CGM-DDR-002). See the session above.

### Safety concerns

- Runaway or oscillating assist: the 0.7 Hz filter, the raw-signal compression cut, torque-mode control and a gain cap of 6 are all required.
- Braking of a 193 kg trailer: the overrun brake must work unpowered; wet pads raise the push to about 120 N; rotors on long, steep descents can rise 170 to 280 K, and the left rotor heats the motor.
- Hitch failure: secondary strap rated 3.8 kN or more, lock indicator, design load above 1,895 N.
- Load placement: the drawbar unloads with the payload center 100 mm behind the deck center; mark a loading zone.
- Motor heat on climbs longer than about 300 m at 8 %.
- 384 Wh LiFePO4 pack: BMS, 20 A fuse, closed vented steel enclosure, charging on a non-combustible surface.
- Pinch points at the 50 mm coupler stroke and the stand; tyres 22.5 mm from the side rails.
- Legal status on public roads is unknown (O2).

### Problems and notes

- `.kit/drawing.py` `project_views` fails on this model: the hidden-line projection yields one zero-length ellipse arc that the SVG exporter rejects. The kit was not changed; `cad/src/sheets.py` has an edge-by-edge copy (`safe_project_views`) that skips the one bad edge, and `cad/src/concept_media.py` uses it for `render_all`. A kit fix is suggested.
- In the exploded view the hitch (4) and load cell (5) are still small at this scale; the GA drawing and cutaway show them in context.
- Masses of bought parts, motor constants, pad friction and hitch joint stiffness are assumed catalog or handbook values; each is listed in CGM-CAL-001, Table 1.
- No TRL 4 material exists in the repo (no tests, build procedures, purchasing lists, firmware or PCB files). `build-log/README.md` is the scaffold stub and was not extended.
- The TRL 2 review listed no unchecked citations, so no web verification was run this session. The TRL 2 sources in CGM-PRB-001 are unchanged.

### Recommended next step

TRL 4 is on hold by Amish's instruction; do not start it. The next step is for Amish to decide items 3 to 6 above and, when ready, O1 and O2. For the record only, TRL 4 would need: a motor datasheet and a bench thermal run of the hub on a simulated 8 % climb; a drawbar and coupler bench rig to measure hitch joint stiffness, loop stability and the overrun brake gain dry and wet; a hitch fit survey across axle types; a test plan and lab test reports (TST, `environment: lab`); and dated build log entries.

## Session 2026-09-25: /populate to a strong TRL 2 (overnight batch)

### What was done

- `docs/01-problem.md` (CGM-PRB-001 v0.2): problem with sourced figures (cargo e-bike prices, unassisted trailer limits, unbraked trailer limits), users, operating environment, constraints, out of scope, prior work with inline sources (Carla Cargo, Biomega Ein, Roland PAXXTER e, coupling-sensor patents), open questions, and a new co-design checklist.
- `docs/03-requirements.md` (CGM-REQ-001 v0.2): 14 measurable requirements (R1 to R14) with targets, verification and a status column against the concept estimates, a design load case and a design route.
- `docs/02-concept.md` (CGM-PRC-001 v0.2): how it works, 16 numbered components, control law, mass and balance, drawbar forces, energy and range, braking, cost, design choices with options, safety section, open questions.
- `cad/src/concept_media.py`: massing model of the trailer (frame, deck, drawbar, hitch, load cell, overrun coupler, motor and idler wheels, brakes, enclosure, pack, controller, control board, harness, lights and flag, stand), with a grey towing bicycle and a grey 150 kg load as hero context and the 1.75 m scale figure.
- `media/`: `hero.png`, `concept-blueprint.png`, `.pdf` and `.svg`, `exploded.png` (callouts 1 to 16), `cutaway.png`, `flow.png` (energy per 10 km loaded trip, estimates), `model.glb` and `viewer.html`. Temporary `media/_views*` folders removed.
- `bom/bom.csv`: 18 lines with indicative prices, numbered to match the exploded view; `bom/bom-notes.md` updated to say so.
- `README.md`: hero image and links line inserted before "Problem"; Concept, Key components and Safety sections updated to match the precis.
- `docs/pdf/`: branded PDFs of the three controlled documents.

### Key results (estimates, to be checked at TRL 3)

| Quantity | Estimate | Requirement |
| --- | --- | --- |
| Payload and deck | 150 kg on 1,200 x 700 mm (0.84 m²) | R1: frame strength unverified |
| Empty trailer mass | about 38 kg (steel frame) | **R8 (35 kg) not met** |
| Pull felt on the flat, G = 4 | about 4 N of about 20 N | R4 met on paper |
| Pull felt on 8 % at 8 km/h | about 33 N of about 165 N; motor about 290 W, 34 N·m | R3 force met; **thermal unverified** |
| Pack energy on the design route | about 14 Wh/km | |
| Range per charge, 384 Wh LiFePO4 | about 24 km hilly and loaded, about 45 km flat | R2 (20 km) met |
| Braking force needed at 3 m/s² | about 560 N from the trailer; overrun brake sized for about 460 N at 100 N push | R6 by design; gain unverified |
| Hitch down load | about 9 kg, payload centered | R10 met |
| Size | about 2.5 m long hitched, about 910 mm wide | R9 met |
| Parts cost | about $965 including charger | **R12 ($900) not met, about 7 % over** |

Requirements not met or at risk:

- **R8 (mass) not met:** about 38 kg against 35 kg with a steel frame; aluminium would give about 33 kg.
- **R12 (cost) not met:** about $965 against $900.
- **R7 (hitch to common bikes) at risk:** the hitch covers quick-release and 12 mm thru-axle wheels; nutted axles, some hub gears and some rear-motor e-bikes need adapters. The pitch's "fits any bicycle" is therefore stronger than the concept supports.
- **R3 (hills) thermal part unverified:** the motor runs at about 290 W against a 250 W continuous rating on the design climb.
- **R4 and R6 unverified:** the proportional loop's stability and the overrun brake gain are TRL 3 calculations.

### Proposed, awaiting Amish

Update: all items below that carried a recommendation were decided by Amish, 2026-09-25: go with recommendation (CGM-DDR-001). Item 8 had none and stays open (O1).

1. **Budget.** Parts are about $65 over. Options: (a) raise `budget_usd` to $1,000; (b) cut cost with salvaged 20 in wheels and brakes and a lighter enclosure to reach about $900; (c) drop side boards and lights from the prototype (not recommended; lights are safety items). Recommendation: (b), then (a) if needed. `project.yaml` is unchanged.
2. **Battery.** Option A: 36 V class LiFePO4, 384 Wh, about $180 (scaffold choice, meets R2, more thermally stable under a load). Option B: the portfolio's SwapCell pack (48 V class, about 468 Wh, about $370, CAN host heartbeat, 48 V drive), which suits shared fleets but adds about $190. Recommendation: A, with a SwapCell variant later for fleets.
3. **Frame material.** Welded steel (cheap, local, about 38 kg, misses R8), aluminium (about 33 kg, about $60 more, TIG welding) or a bolted steel kit. Recommendation: steel for the first prototype and relax R8 to 40 kg, or revisit.
4. **Drive layout.** One 250 W hub in the left wheel (recommended), two 125 W hubs, or a third central drive wheel.
5. **Control law.** Proportional assist with a selectable fixed gain, default G = 4 (recommended), versus a closed loop to a small set tension.
6. **Brakes.** Mechanical overrun coupler on both disc brakes plus electronic assist cut (recommended), versus an electrically actuated brake or a cable from the bike's lever.
7. **Pitch wording.** "Fits any bicycle" and "almost no added load" are strong: the hitch fits most quick-release and thru-axle bikes, and the rider feels about 4 N on the flat but about 33 N on an 8 % climb. Options: keep the pitch as an aim, or soften to "fits most bicycles" and "a fraction of the load". Recommendation: soften at the next pitch review. `project.yaml` pitch and problem are unchanged; the sourced numbers support the problem statement as written.
8. **First users and region** for co-design (market traders, a trades cooperative or a community food bank).
9. **Handcart mode** left out of scope for now.

### Safety concerns

- Unintended push or runaway assist, which can shove the bike into traffic or jackknife it: assist only in tension, cut within 100 ms on compression, standstill, overspeed or any sensor fault; controller in torque mode with its own current limit; no throttle.
- Braking of a 188 kg trailer, well above the 45 to 60 kg unbraked limits in ASTM F1975 and EN 15918: the overrun brake is mandatory and must work unpowered; rotor heating on long descents is unchecked.
- Hitch failure: a secondary safety strap and a clear lock indicator are required; hitch design loads are not yet calculated.
- 384 Wh LiFePO4 pack: BMS, fuse, closed vented enclosure, charging on a non-combustible surface.
- Load tipping, pinch points at the sliding coupler and stand, and visibility of a long combination.
- Legal status of a motorized trailer on public roads is unknown in every target country.

### Problems and notes

- The kit renderer's labels for the orthographic views read "Front view" and "Right view"; for this trailer the "Front view" is the side elevation. This comes from `.kit/drawing.py` and was not changed.
- In the exploded view the hitch (4) and load cell (5) are small, so their callouts nearly cover them; the precis and cutaway show them in context.
- The cutaway cuts on the trailer center line, so the left-offset hitch and most of the load cell are cut away; the pack, controller, board and overrun coupler show clearly.
- The legacy `cad/src/model.py` placeholder is untouched (TRL 3 work).
- While stopping a stale render of this repo, a `pkill -f concept_media.py` command was run that could also have stopped concept renders for other repos running in parallel in the same overnight batch. Those repos' media should be checked for completeness.

### Recommended next step

Review this note and the media, then decide items 1 to 3 and 7. If approved, run `/advance-trl3` to check the assist loop stability, motor heating, overrun brake gain, hitch loads and frame stress by calculation, and produce the parametric model and drawing sheet.

## Session 2026-09-26: product appearance model and photoreal renders

Amish chose this repo for the first batch of product renders on 2026-09-26.

### What was added

`cad/src/product_model.py` exposes `product_parts()` (80 parts: 60 shell, 9 internal, 2 accessory, 9 context), `TITLE` and `RENDER_VIEWS` (hero, exploded, and a detail view of the trailer alone from the drawbar side). It reuses PARAMS, derived(), drawbar_points() and build_parts() from `cad/src/model.py`; the chassis frame, drawbar and harness are the model.py solids, and every other part keeps the model.py position and main dimensions. It adds:

- Deck and boards: rounded plywood deck with two aluminium tie-down tracks; off-white side and end boards with hand slots, aluminium corner caps, teal trim bands and a raised CARGOMULE badge on each side.
- Drawbar load cell: S-shaped cell body in the model.py envelope, pinned clevises, gauge plugs and cable, under a clear polycarbonate guard with teal end rings.
- Overrun coupler: sleeve, rubber gaiter over the sliding end, filleted damper housing, brake lever and equalizer, bolts and brake cables to the calipers.
- Hitch: filleted axle plate and nut, joint with a ribbed rubber boot, arm, locking pin with a green lock indicator, and the secondary safety strap to the bicycle's chainstay.
- Wheels and brakes: tyres, rims and laced spokes as separate parts; the 250 W hub motor shell with spoke flanges, a teal cover ring, bolts and cable exit; the idler hub; slotted 180 mm rotors and calipers.
- Enclosure: closed, filleted galvanized box with a parting seam, louvre vents, screws, cable glands, a warning label, a clear inspection window onto the pack, and on its front face the key switch, the knurled assist gain dial with its 2 to 6 scale, a lit green status light and a capped charge port. Inside: the pack with its label, a finned controller and the control board with components.
- Lights and stand: lit red rear lights in black housings, amber side and drawbar reflectors, a fabric safety flag on its pole, and the stand leg with a rubber foot.
- Accessory: the off-trailer charger and lead (BOM 17), shown in the exploded view only.
- Context (not in the BOM): a simple bicycle whose rear axle sits at the hitch height (340 mm), the shared clay mannequin in the "ride" pose placed from its landmarks so the feet meet the pedals, the seat meets the saddle and the hands meet the grips, and a small strapped load of a crate and two cartons.

`README.md` now shows `media/render-hero.png` and links `media/render-exploded.png`; the orchestrator produces both files. Matplotlib self-check previews were made in `/tmp/cargomule-prod/` (outside the repo).

### Differences from model.py (Proposed, awaiting Amish)

1. **Closed enclosure with a parting seam.** model.py draws an open-top box so the section views show the pack; BOM line 10 calls for a lockable lid. The appearance model closes the box and shows a seam 28 mm below the top, but the top sits against the frame rails, so a top lid could not open in place. Proposed, awaiting Amish. Recommendation: specify a bolted bottom or front access panel (or a removable box on slides) at the next design step, and keep the lock on the key switch.
2. **Controls on the enclosure front face.** The key switch, gain dial, status light and charge port are placed on the face toward the drawbar, where the rider can reach them at a stop. The concept does not yet say where they go. Proposed, awaiting Amish. Recommendation: accept this location.
3. **Clear guard over the load cell and an inspection window on the enclosure.** Neither is in the BOM. The guard shields the cell and its cable from spray and stones; the window lets the render show the pack. Proposed, awaiting Amish. Recommendation: adopt the guard (a short polycarbonate tube, a few dollars under BOM line 5), and treat the enclosure window as render-only: a plain steel side is cheaper, keeps the pack out of the sun and keeps the enclosure robust.
4. **Finish and small parts.** Graphite powder coat for the frame (BOM line 1 says painted), off-white faced side boards with hand slots and name badges (BOM line 2 says sealed plywood), deck tie-down tracks in place of loose eyes on the deck, a rubber gaiter on the coupler and a drawbar reflector. Proposed, awaiting Amish. Recommendation: keep the plywood and paint of the BOM for the prototype; treat the faced boards, tracks and badges as finished-product styling.
5. **Hero composition.** With the bicycle and rider in the scene the trailer fills about half of the hero frame. The views cannot frame a single subsystem, so the "detail" view shows the trailer alone from the front left, with the load cell, coupler and hitch nearest the camera. Proposed, awaiting Amish. Recommendation: accept; if a tighter shot of the load cell is wanted, add a close-up camera option to the kit renderer rather than changing the model.

### Status

This is an appearance model only: no tolerances, no fabrication detail, nothing past TRL 3. `trl: 3` and `trl_target: 3` are unchanged, and TRL 4 remains on hold. model.py, the BOM and the other documents were not edited.

## Session 2026-09-27: kit 1.5.0 and image quality

- Kit 1.5.0 synced: STANDARDS v1.5 (sections 12 to 15: product renders, storefront images and image quality, public release, authorship and signing), `.kit/cards.py`, `.kit/image_qc.py`, `.kit/release_gate.py`, issue templates, and the `/render-product` and `/release` commands. `CLAUDE.md` now matches `.kit/CLAUDE.md`.
- Every `media/render-*.png` recaptioned from its original render with the new layout: the title, concept label and repository sit in a band above the render and the view note in a band below it, each line wrapped to the image width, so no text overlaps other text or the render or runs off the image. `media/card.png` and `media/social-preview.png` regenerated with the same rules.
- `python .kit/image_qc.py` and `python .kit/release_gate.py` pass. trl stays 3.

## 2026-10-02: photoreal renders redone on the constructable design

Rendered with Blender Cycles on Amish's Mac from the updated appearance model (`cad/src/product_model.py`); captioned with `.kit/photo_caption.py`; `media/card.png` and `media/social-preview.png` regenerated with `.kit/cards.py`. Views: hero, exploded, detail. image_qc passes. Appearance deviations are those logged above as proposed, awaiting Amish.

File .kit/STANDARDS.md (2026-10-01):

---
doc_id: OHP-STD-001
title: Documentation and drawing standard
project: Open Hardware Portfolio
doc_type: Standard
version: "1.7"
status: Released
date: 2026-09-30
author: Amish Chadha
license: CC-BY-SA-4.0
revisions:
  - version: "1.0"
    date: 2026-09-24
    author: Amish Chadha
    change: First release of the standard
  - version: "1.1"
    date: 2026-09-24
    author: Amish Chadha
    change: Adopt Technology Readiness Levels (section 9) for project maturity
  - version: "1.2"
    date: 2026-09-24
    author: Amish Chadha
    change: Portfolio phase cap (section 10), concept media standard (section 11), CLAUDE.md guardrails
  - version: "1.3"
    date: 2026-09-24
    author: Amish Chadha
    change: Scale figure, interactive 3D viewer and flow diagrams added to concept media; session slash commands
  - version: "1.4"
    date: 2026-09-26
    author: Amish Chadha
    change: Every sheet and render names the project and its GitHub repository; overall dimensions, ISO centre lines and 300 dpi PNG on sheets; titles name the device and view labels state the viewing direction; optional photoreal renders with Blender
  - version: "1.5"
    date: 2026-09-27
    author: Amish Chadha
    change: Product renders (section 12), storefront images and image quality check (section 13), public release and release gate (section 14), authorship, citation and commit signing (section 15)
  - version: "1.6"
    date: 2026-09-29
    author: Amish Chadha
    change: Licensing metadata with REUSE (section 16), Zenodo DOI and Software Heritage archiving (section 17), release gate checks REUSE and a single CITATION.cff license, archive.py
  - version: "1.7"
    date: 2026-09-30
    author: Amish Chadha
    change: Concept and constructable design states; design decisions register (DEC) kept apart from the build plan; prototype build plan (BLD, section 18) with pictures by component is required TRL 3 evidence; every repo targets TRL 3 during the populate phase; build_views.py; /to-trl3 and /build-plan commands
---

# Documentation and drawing standard

Every project in the portfolio uses this standard, so that each precis, write-up and sketch looks the same and carries its own version history. The standard ships as a kit in each repo's `.kit/` folder. The kit version is in `.kit/KIT_VERSION`.

## 1. Document types and IDs

Every controlled document has a unique ID in the form `PRJ-TYP-NNN`.

- `PRJ` is the three-letter project code listed in section 7.
- `TYP` is the document type code from the table below.
- `NNN` is a sequence number within that project and type, starting at 001.

| Code | Type | Typical file |
| --- | --- | --- |
| PRC | Design precis | `docs/02-concept.md` |
| PRB | Problem statement | `docs/01-problem.md` |
| REQ | Requirements | `docs/03-requirements.md` |
| CAL | Calculation or sizing note | `docs/04-calcs/*.md` |
| DDR | Design decision record | `docs/decisions/*.md` |
| BOM | Bill of materials | `bom/bom.csv` |
| DWG | Drawing or sketch sheet | `cad/drawings/*.svg` |
| BLD | Prototype build plan (section 18) | `docs/05-build-plan.md` |
| DEC | Design decisions register (section 18) | `docs/06-design-decisions.md` |
| TST | Test plan or test report (front matter adds `environment: lab` or `relevant`) | `docs/05-tests/*.md` |

Example: `TBK-PRC-001` is the ThermaBrick design precis.

## 2. Revision scheme

| Artifact | While in draft | When released | Change after release |
| --- | --- | --- | --- |
| Documents | 0.1, 0.2, 0.3 ... | 1.0 | 1.1 for minor edits, 2.0 for a design change |
| Drawings | Rev P1, P2 ... (preliminary) | Rev A | Rev B, C ... |

- Every change to a controlled document adds a row to its revision history before the commit.
- The `version` field in front matter always equals the newest row in `revisions`. The renderer rejects a document where they differ.
- Status is one of `Draft`, `In review`, `Released` or `Superseded`. Draft and In review documents print with a status band on every page.
- Every release is tagged in Git as `<doc_id>/v<version>`, for example `TBK-PRC-001/v1.0`. Drawings are tagged `TBK-DWG-001/revA`.
- Git history is the full audit trail. The in-document revision table is the human-readable summary.

## 3. Document front matter

Every Markdown document under version control starts with this block:

```yaml
---
doc_id: TBK-PRC-001
title: ThermaBrick design precis
project: ThermaBrick
doc_type: Precis
version: "0.1"
status: Draft
date: 2026-09-24
author: Amish Chadha
license: CERN-OHL-S-2.0
revisions:
  - version: "0.1"
    date: 2026-09-24
    author: Amish Chadha
    change: Initial draft
---
```

Quote version numbers so YAML keeps `1.0` as text instead of turning it into a number. List revisions newest last.

## 4. Writing style

- Chicago Manual of Style.
- No em dashes. Restructure the sentence instead.
- Lead each section with its conclusion, then support it.
- SI units throughout, in the form `12 kW`, `450 °C`, `3.2 m`. Imperial values may follow in parentheses.
- Number every figure and table ("Figure 2", "Table 1") and give each a caption.
- State every assumption in the calculation that depends on it.
- Put safety notes in a blockquote starting with **Safety:**.

## 5. Visual identity

| Element | Specification |
| --- | --- |
| Typeface | IBM Plex Sans for text, IBM Plex Mono for code and values (SIL Open Font License, bundled in `.kit/fonts`) |
| Ink | `#111827` |
| Secondary text | `#4B5563` |
| Rules and grid | `#D1D5DB` |
| Accent (one only) | `#0F766E` teal |
| Document page | US Letter, 20 mm margins |
| Drawing sheet | ANSI B landscape (431.8 x 279.4 mm) |
| Footer | Document ID, version, status, license and designmolecule.com on every page |

## 6. Drawing and sketch conventions

- Units are millimeters unless the title block says otherwise.
- Third-angle projection, marked with the symbol in the title block.
- Line weights: visible outlines 0.5 mm, hidden lines 0.25 mm dashed, center lines 0.18 mm chain.
- The title block contains the project, title, drawing number, revision, scale, units, projection, sheet, author, date, material or notes, and license.
- Every sheet and every render names the project and its GitHub repository (from `repo:` in `project.yaml`), at the top of the sheet and in the title block, so a printed or forwarded sheet is never anonymous.
- The drawing title names the device, not only the drawing type (for example "Handheld near-infrared resin scanner: general arrangement").
- Every view label states its scale and viewing direction (for example "Scale 1:1; side elevation looking along +Y"), and every isometric or render states where it is seen from.
- Orthographic views generated with `add_ortho` carry overall dimensions (length and depth on the top view, height on the front view) and ISO 128 centre lines on cylinders; hidden lines are dashed. Tolerances are not shown before TRL 4.
- Sheets are exported as SVG, PDF and a 300 dpi PNG.
- The revision table in the top right of the sheet lists every revision.
- Concept sketches use the same sheet and title block and carry the label "CONCEPT, NOT FOR FABRICATION".
- Geometry comes from `cad/src/*.py` (build123d). Sheets are generated by `.kit/drawing.py` and never edited by hand.

## 7. Project codes

| Code | Project | Code | Project | Code | Project |
| --- | --- | --- | --- | --- | --- |
| TBK | ThermaBrick | PCF | PicoFlow | HLT | HelioLite |
| CCB | CharCube | DRN | DustRunner | TRT | TremorTrace |
| STC | StepCue | FXH | FlexHand | CPD | ColdPod |
| SCL | SunClave | STR | SteamRoot | GGD | GrainGuard |
| SDL | SeedLine | ZBX | ZeerBox | RMS | RootMesh |
| DWD | DewDrive | SSK | StillStack | PPR | PotPress |
| WWT | WaterWatch | LMF | LumaFlow | FCL | FieldCell |
| CNP | ConePro | CVC | CulvertCrawl | EGD | EmberGuard |
| SNF | SnapFrame | CGM | CargoMule | SCM | StepClimber |
| SWC | SwapCell | PLP | PalletPilot | FTK | FlatTrike |
| WWK | WaterWalker | GRR | GrowRider | SSP | SunSpoke |
| SGN | StepGen | PBX | PowerBox | WML | WasteWise-ml |
| WSC | WasteWise Scan | RFE | ReflowEconomy | | |
| OHP | Portfolio-wide | | | | |
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

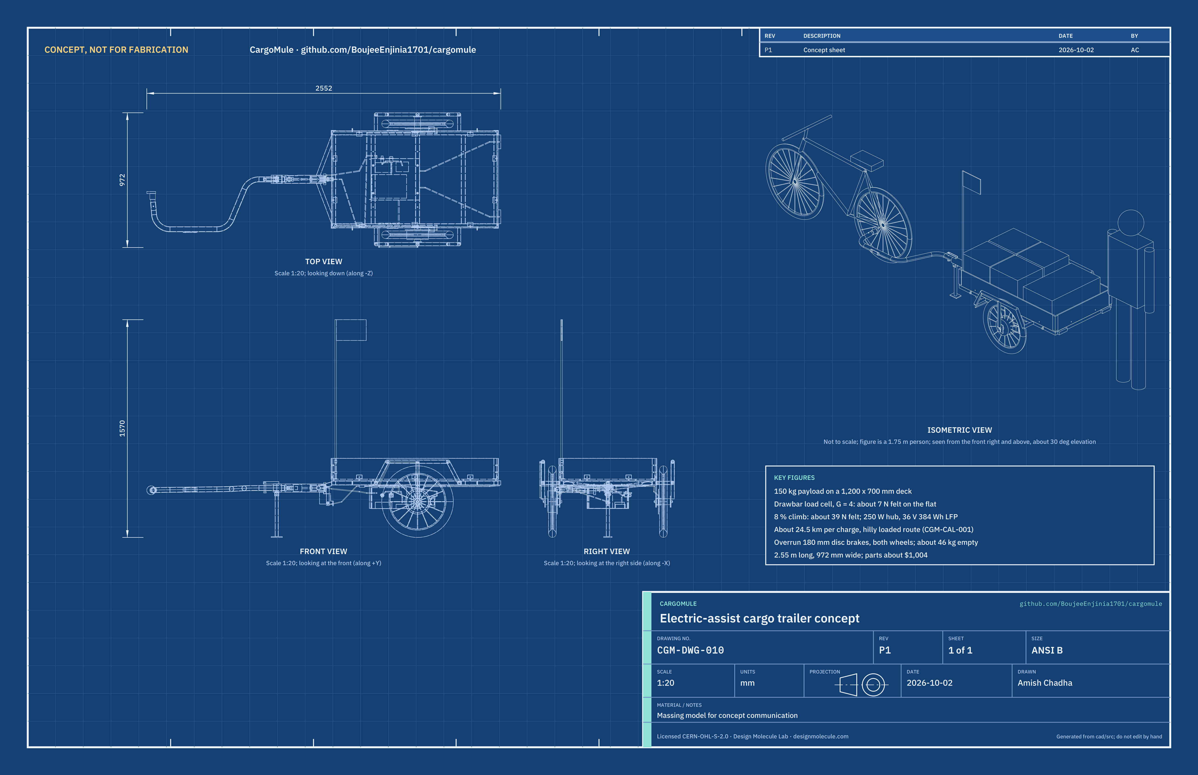
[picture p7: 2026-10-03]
media/concept-blueprint.png

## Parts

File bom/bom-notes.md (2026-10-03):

# BOM notes

- Item numbers 1 to 16 match the callouts in `media/exploded.png`. Items 17 (charger) and 18 (hardware) have no callout.
- Costs are indicative 2026 small-quantity prices in USD for a TRL 3 paper design, not quotes. Suppliers are given by type; no supplier has been selected.
- Item 9 is priced per wheel (quantity 2).
- Value-engineering target: USD 1,000 (`budget_usd` in `project.yaml`, a hypothetical control target, not a limit). Estimated cost of the constructable design: USD 1,004 (USD 4 over the target), checked by `docs/04-calcs/sizing.py` (CGM-CAL-001, I1).
- Amish decided on 2026-09-25 to cut cost first and then raise the budget from $900 to $1,000 (CGM-DDR-001, D1). The cuts are on items 8 (idler wheel, $55 to $30), 9 (calipers, $30 to $20 each) and 10 (smaller 0.8 mm enclosure, $30 to $25), saving $50. TRL 3 sizing added $54 (arch frames on item 1, repriced plywood on item 2, the larger offset drawbar on item 3, a 3.8 kN strap on item 4, an overload stop on item 5 and the 7.7:1 lever on item 6).
- Amish accepted the TRL 3 recommendations on 2026-09-25 (CGM-DDR-002). Item 9 moved to 180 mm rotors with metallic pads, $20 to $25 per wheel, so the total rose from $969 to $979. The target stays $1,000.
- On 2026-10-01 the design was made constructable (CGM-DDR-003, Table 1 accepted by Amish on 2026-10-02). Items 2 (aluminium corner pieces and board brackets, +$10), 5 (threaded cell ends, rod end and clevis in place of pinned clevises, -$5), 6 (housing, spring cage, pull rod, lever, cable splitter, +$8) and 18 (rivet nuts, +$5) were repriced, and items 1, 3, 7, 9, 10, 15 and 16 respecified at the same price. The total rose from $979 to $997. The target stays $1,000.
- On 2026-10-02 Amish's decisions were carried into the BOM: item 14 now names the keyed on-off switch and a 3-pin charge socket with a hinged cap on the enclosure's right wall near the front (CGM-DDR-003 A2; socket about $4 added, $30 to $34), item 15 adds an amber drawbar reflector on two hose clips (review note 2026-09-26 item 4; about $3, $30 to $33), and item 10 gains the two wall holes at the same price. Prices are typical small-quantity catalog prices, not quotes. The total rose from $997 to $1,004, $4 over the value-engineering target, which stays $1,000.
- Masses in the notes column come from CGM-CAL-001, section A.

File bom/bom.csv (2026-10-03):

item | qty | spec | supplier | unit_cost_usd | make_buy | notes
1 Chassis frame | 1 | Welded mild steel: 30 x 30 x 1.5 mm box section side rails (ends capped), end rails and three crossmembers, 28 x 1.5 mm A-frame nose bars fishmouthed onto the coupler housing, 25 x 1.5 mm wheel arch frames carrying the outer dropouts, 5 mm dropout plates with 10.2 mm axle slots (inner plates with caliper tabs), tie-down eyes; painted | Local steel stockist and community or trade welder | 95.00 | make | TRL 3 price: about $45 steel, $40 welding labor and consumables, $10 paint; about 13.0 kg from the model (CGM-CAL-001 A1); dropout tabs and slots per CGM-DDR-003
2 Deck and side boards | 1 | 12 mm exterior plywood deck 1,200 x 700 mm on 16 M6 countersunk bolts; removable 9 mm plywood side and end boards 150 mm high held by 4 aluminium corner pieces and 10 aluminium angle brackets (30 x 30 x 3 mm) with M6 wing nuts; exterior sealer | Timber merchant | 77.00 | make | One 12 mm sheet about $38, 9 mm part sheet about $15, aluminium angle and wing bolts $10, sealer $6, eyes $8; fittings added per CGM-DDR-003; about 8.9 kg
3 Drawbar | 1 | S355 steel tube 38 mm OD x 2.5 mm, cut 1,320 mm, three bends of 115 mm radius to an offset run 360 mm left of the center line and a straight rear part on the center line; welded M10 end plug; 12.2 mm overload pin hole | Local steel stockist and fabricator | 35.00 | make | Upsized from 32 x 2 mm at TRL 3 (CGM-CAL-001 G3, G4); bent per CGM-DDR-003; about 3.0 kg
4 Universal axle hitch | 1 | Axle-end plate for 9 mm quick release and 12 mm thru-axle (matching hitch axle per thread pitch), three-axis elastomer or ball joint, locking pin with visible lock indicator, secondary safety strap rated 3.9 kN or more | Bicycle trailer parts supplier | 50.00 | buy | Strap rating from CGM-CAL-001 G6
5 Drawbar load cell and amplifier | 1 | S-type load cell 1 kN (100 kg), 2 mV/V, IP66, M10 threaded ends, body no more than 54 mm across its diagonal; M10 rod end with spherical eye and a clevis with M8 pin; 24-bit HX711-class amplifier potted in the enclosure | Electronics distributor | 27.00 | buy | Cell about $20, rod end and clevis $4, amplifier $3; mounted inside the coupler housing per CGM-DDR-003
6 Overrun brake coupler | 1 | Fabricated: 60.3 x 2.0 mm steel tube housing 370 mm with rear flange, side window, slotted fork with closed front end (overload stop), stand clevis and lever cheeks, welded into the frame nose; two acetal bushings 38 mm bore; spring cage with bulkhead and bolted end cap; M10 pull rod, spherical washer and nut; preload spring about 30 N; M12 shoulder bolt overload pin; 20 x 6 mm brake lever 7.7:1 with friction washers; cable splitter and three brake cables | Local fabricator with bought spring and damper | 58.00 | make | Lever ratio and stroke from CGM-CAL-001 F3; mechanical so it brakes with the power off; friction damping in place of a hydraulic damper (CGM-DDR-003)
7 Hub motor wheel | 1 | 36 V 250 W geared front-style hub motor, 100 mm spacing, disc mount, Hall sensors, winding about 230 rpm at 38 V, 10 mm axle flats, cable exit on the non-disc side, laced into a 20 in (ETRTO 406) rim with a 20 x 2.15 in tyre; torque arm | E-bike parts supplier | 160.00 | buy | Winding and constants to confirm from the datasheet (CGM-CAL-001 C1); buy as a kit that includes a torque arm (CGM-DDR-003)
8 Idler wheel | 1 | 20 in (ETRTO 406) front wheel with 100 mm disc hub and 20 x 2.15 in tyre, salvaged or budget grade | Used bicycle parts or community bike shop | 30.00 | buy | Cost cut per CGM-DDR-001 D1 (was $55)
9 Mechanical disc brakes | 2 | Budget cable-actuated caliper with 180 mm rotor, metallic (sintered) pads and a post-mount adapter to suit the dropout tab | Bicycle parts supplier | 25.00 | buy | Price per wheel; cost cut per CGM-DDR-001 D1 (was $30), then 180 mm rotors and metallic pads per CGM-DDR-002 (+$5 per wheel); cables and splitter are in item 6; CGM-CAL-001 F3, F4, F6
10 Battery and electronics enclosure | 1 | Folded 0.8 mm galvanized steel box 350 x 300 x 170 mm, closed top bolted up to the crossmembers by 4 M6 bolts with doubler strips, front door hinged along its bottom edge with a keyed lock and gasket, vent low on the rear face directed away from the load, cable glands; a 19 mm and a 24 mm hole in the right wall near the front for the key switch and charge socket | Local fabricator or sheet metal shop | 25.00 | make | Smaller and lighter per CGM-DDR-001 D1 (was 1.2 mm, 400 x 460 mm, $30); door and fixing per CGM-DDR-003; about 3.0 kg; right wall holes per CGM-DDR-003 A2 (2026-10-02), same price
11 Battery pack | 1 | 12S1P LiFePO4, 38.4 V nominal, 10 Ah, 384 Wh, BMS with 15 A discharge, cell protection and low-temperature charge cutoff, about 4.2 kg | Battery supplier | 180.00 | buy | 36 V class LiFePO4 per CGM-DDR-001 D2
12 Motor controller | 1 | 36 V sine-wave controller, 15 A battery and 30 A phase current limits, torque (current) mode input, Hall sensor input, IP65 | E-bike parts supplier | 35.00 | buy | Current limits from CGM-CAL-001 C2
13 Control board | 1 | Microcontroller board with load cell input, Hall speed input, key switch input, gain selector (2 to 6), status LED, in a potted housing | Electronics distributor | 30.00 | buy | Firmware is a sketch at most at TRL 3
14 Wiring harness fuse and key switch | 1 | Keyed waterproof connectors, 20 A fuse in a sealed holder, 2.5 mm2 cable, spiral wrap; keyed on-off switch for a 19 mm panel hole and a 3-pin charge socket with hinged cap for a 24 mm panel hole, both on the enclosure's right wall near the front, with their leads | E-bike parts supplier | 34.00 | buy | Key switch and charge socket on the enclosure's right wall (CGM-DDR-003 A2, decided 2026-10-02): socket and cap about $4 added (typical small-quantity price for a 3-pin panel charge socket); about 0.55 kg in all
15 Lights reflectors and flag | 1 | Two rear red LED lights powered from the pack through a DC-DC converter, on M5 screws into the rear rail; side and rear reflectors; amber drawbar reflector about 100 x 24 mm on two stainless hose clips on the drawbar's outward run; flag on a 12 mm pole, 1.15 m above the deck, in two clips on the left side board at the front | Bicycle parts supplier | 33.00 | buy | Drawbar reflector added (decided 2026-10-02, review note 2026-09-26 item 4): about $3 with clips (typical bicycle reflector price), about 0.05 kg; about 0.55 kg in all
16 Parking stand | 1 | 25 x 2 mm steel tube leg 316 mm with an 80 x 60 x 6 mm foot, pivoting on an M10 bolt in a clevis under the coupler housing; folds back under the housing | Local fabricator | 15.00 | make
17 Charger | 1 | Certified LiFePO4 charger, 43.8 V, 4 A, mains input | Battery supplier | 40.00 | buy | Not on the trailer; no exploded-view callout
18 Hardware and consumables | 1 | Bolts, nyloc and wing nuts, 20 M6 and 4 M5 rivet nuts, cable clips and ties, end caps, dielectric grease, threadlocker | Local hardware shop | 30.00 | buy | No exploded-view callout; rivet nuts added per CGM-DDR-003

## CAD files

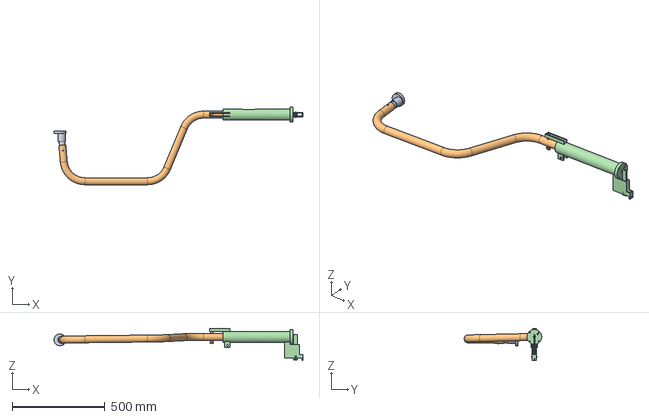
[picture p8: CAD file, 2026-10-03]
cad/step/drawbar-assembly.step
1345.0 x 419.0 x 174.0 mm

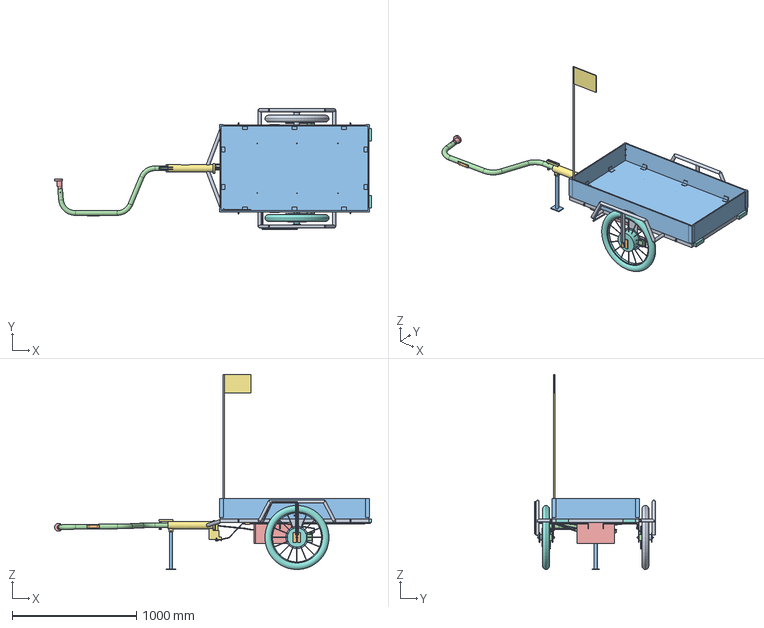
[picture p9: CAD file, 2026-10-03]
cad/step/cargomule-assembly.step
2552.0 x 971.5 x 1570.0 mm

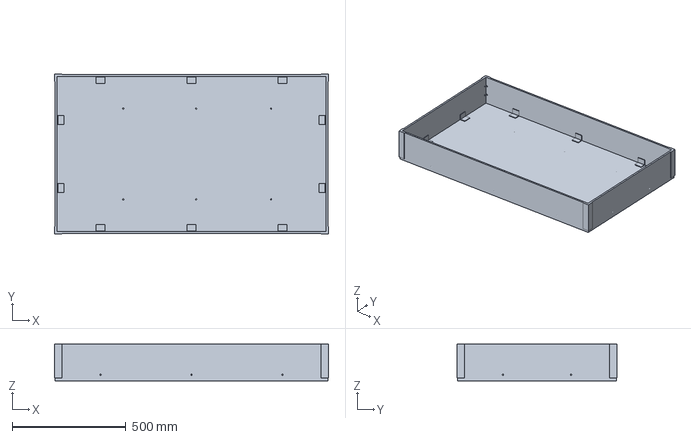
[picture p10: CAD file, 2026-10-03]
cad/step/deck.step
1206.0 x 706.0 x 162.0 mm

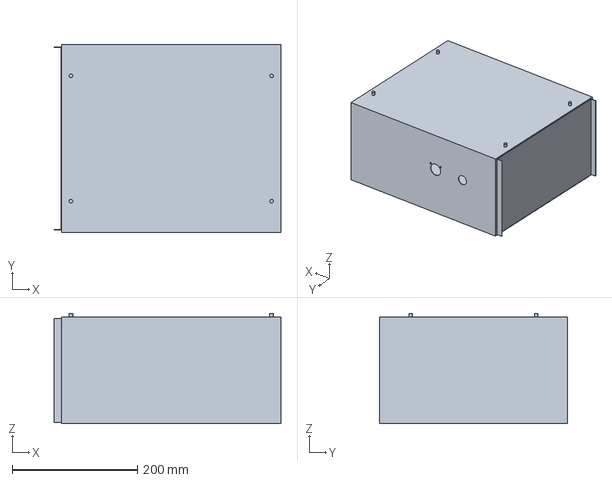
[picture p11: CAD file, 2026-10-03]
cad/step/enclosure.step
362.0 x 300.0 x 176.0 mm

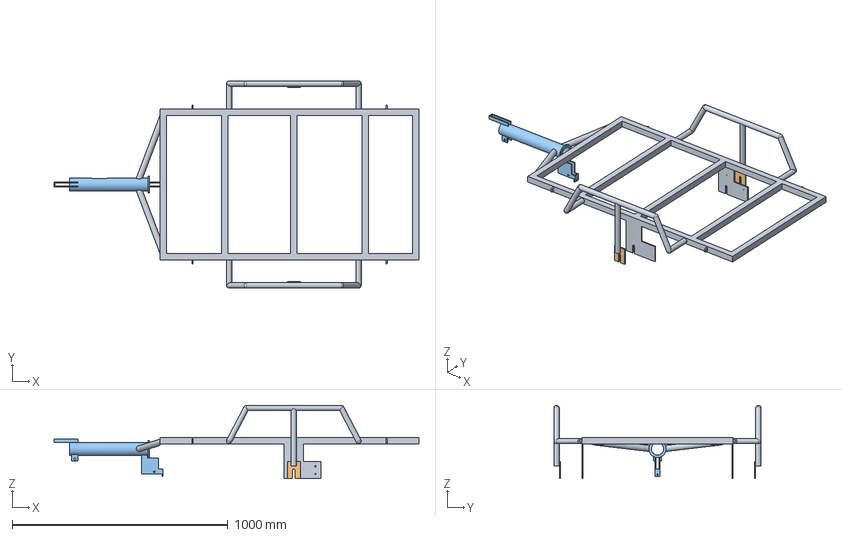
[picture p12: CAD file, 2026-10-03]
cad/step/frame.step
1691.5 x 960.0 x 340.5 mm

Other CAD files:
cad/stl/cargomule-assembly.stl
cad/stl/deck.stl
cad/stl/drawbar-assembly.stl
cad/stl/enclosure.stl
cad/stl/frame.stl

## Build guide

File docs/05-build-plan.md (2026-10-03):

---
doc_id: CGM-BLD-001
title: CargoMule prototype build plan
project: CargoMule
doc_type: Build plan
version: "0.4"
status: Draft
date: '2026-10-02'
author: Amish Chadha
license: CERN-OHL-S-2.0
revisions:
  - version: "0.1"
    date: '2026-10-01'
    author: Amish Chadha
    change: First build plan, with pictures by component and step; design made constructable (CGM-DDR-003)
  - version: "0.2"
    date: '2026-10-02'
    author: Amish Chadha
    change: "R8 acceptance figure set to the 47 kg prototype cap decided on 2026-10-02 (CGM-DDR-003, A1)"
  - version: "0.3"
    date: '2026-10-02'
    author: Amish Chadha
    change: "Section 2: the Table 1 changes of CGM-DDR-003 accepted by Amish on 2026-10-02"
  - version: "0.4"
    date: '2026-10-02'
    author: Amish Chadha
    change: "Decisions of 2026-10-02 carried in: key switch and charge socket holes in the enclosure's right wall (making sketch, enclosure step and harness step), drawbar reflector (lights step); pictures regenerated; figures from CGM-CAL-001 v0.6"
---

# CargoMule prototype build plan

**Plan, not yet built.** How to build the first proof-of-concept prototype, component by component. Building and testing to it is TRL 4 work. Decisions still to be made are kept in the design decisions register ([docs/06-design-decisions.md](06-design-decisions.md)), not here.

## 1. What you are building

Figure 1. Every component, pulled apart and numbered in build order

*Figure 1. Every component pulled apart and numbered in build order, seen from the left; the bicycle would be on the left.*

The prototype is one CargoMule trailer: a welded steel frame on two 20 in wheels with a plywood deck 1,200 x 700 mm and removable side boards, towed from a bicycle's left rear axle end by a bent steel drawbar. The drawbar's straight rear end slides in a steel tube at the frame's nose, the coupler housing. Inside the housing a load cell measures how hard the bike pulls, and a hub motor in the left wheel pushes in proportion. When the bike slows, the drawbar slides back against a spring and a lever pulls the disc brakes on both wheels. A battery pack, motor controller and control board sit in a steel box under the deck. Figure 1 shows the 20 components in the order you make or fit them. Ten are made in a workshop: the coupler housing, the spring cage and end cap, the dropout plates, the frame, the drawbar, the brake lever, the parking stand, the deck, the boards with their fittings, and the battery enclosure. Everything else is bought and fitted. The work is sawing, drilling, filing and welding steel tube and plate, bending one tube in a tube bender, folding thin sheet, cutting plywood, and wiring bought electrical parts with plug-in connectors. The parts cost about $1,004 from the bill of materials.

> **Safety:** This trailer carries 150 kg behind a bicycle, has a 384 Wh lithium iron phosphate battery and a motor that pushes, and brakes itself with a spring-loaded coupler. Welding, grinding and tube bending need eye, hand and hearing protection and a fire-safe area. The battery stays out of the workshop until stop S3 in section 6, and the trailer is never ridden or towed on a public road as part of this plan. The first loaded tests happen only after every stop in section 6 is passed.

## 2. What changed to make it buildable

The concept showed what the trailer does; some of its parts could not be made, fixed or put together as drawn. Each change below keeps what the trailer does, and all of them are recorded in decision record CGM-DDR-003; Amish accepted the changes in its Table 1 on 2026-10-02.

*Table 1. Changes from the concept.*

| Component | The concept had | The buildable design has | Why |
| --- | --- | --- | --- |
| Load cell and coupler | A load cell on pinned ends in the drawbar line, ahead of a separate sliding coupler  | The drawbar slides in two bushings in the coupler housing; the load cell is inside the housing, in line with a pull rod and a spring (Figure 5) | A pinned load cell cannot hold the drawbar up; the bushings now carry its weight and bending, and the cell sees only pull and push |
| Assembly of the coupler | Parts that could not be put in from either end | The spring, rod and cell go in from the rear as one cartridge; a pin joins them to the drawbar through a side window (Figure 6) | Every part goes in and comes out with hand tools |
| Overload stop | None that could be built | A closed slot on top of the housing; a pin through the drawbar sits 0.5 mm behind its end (Figure 3) | It also stops the bent drawbar turning in its bushings |
| Brake lever | A block with no pivot | A lever on a bolt between two plates under the housing, 7.7 to 1, with friction washers for damping (Figure 15) | Same ratio as the concept; nothing else to mount |
| Drawbar | Sharp corners and a short straight end | One tube with three bends made in a tube bender (Figure 12) | A fabricator can bend it in one piece |
| Nose of the frame | Nose bars meeting in a solid ball | Nose bars welded to the sides of the coupler housing (Figure 11) | The housing is the nose |
| Battery enclosure | An open box with a lid it could not open, no fixing | A closed box bolted up into two crossmembers, with a front door the pack slides out of (Figure 22) | The pack can be fitted and removed; the box hangs from the frame |
| Brakes and dropouts | Calipers running into the motor; no axle slots; no torque arm | Calipers on tabs of the inner dropout plates, slotted dropouts and a torque arm (Figure 8) | Standard bicycle parts fit |
| Deck, boards, lights, flag, stand | No fixings | Bolts into rivet nuts, wing-nut brackets, pole clips and a pivoted stand (Figure 20) | Everything is held, and the boards still come off by hand |

The constructable trailer weighs 46.3 kg empty, 3.0 kg more than the concept estimate, mostly in the coupler and the fixings.

## 3. Making the components

Make and check each component before the assembly step that needs it. Sizes are in millimetres. "Front" is toward the bicycle, "left" and "right" are as seen sitting on the bicycle, and heights are above the ground with the trailer on its wheels. Workshop tolerance is 0.5 mm unless a step says otherwise; drawings do not carry tolerances before TRL 4.

### 3.1 Coupler housing

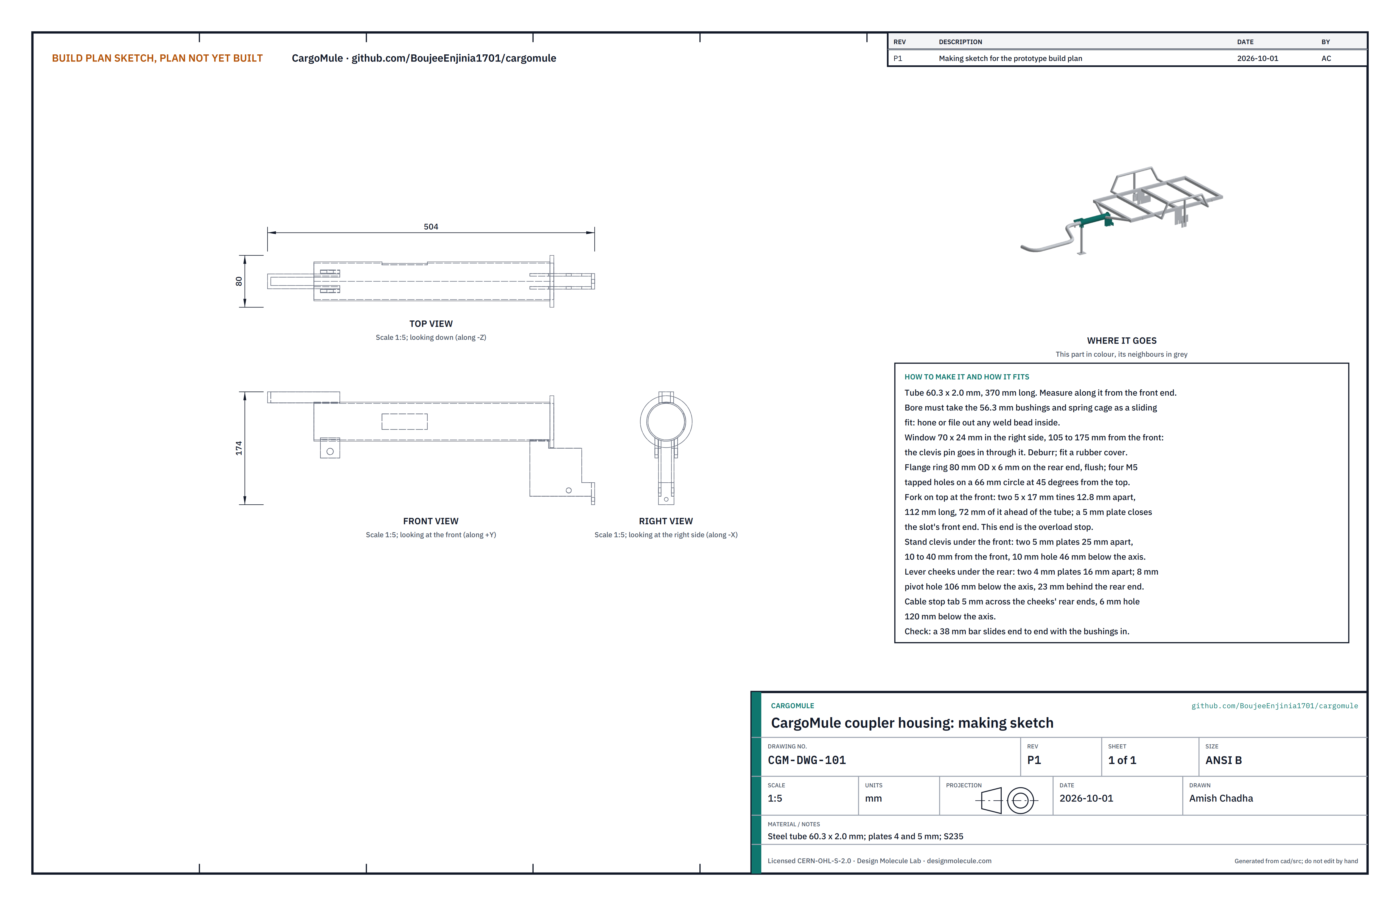
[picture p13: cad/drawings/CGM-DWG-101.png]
Figure 2. Making sketch of the coupler housing


*Figure 2. Coupler housing making sketch (CGM-DWG-101).*

**What it is and what it is made from.** The steel tube at the front of the frame that the drawbar slides in, with the load cell inside it, and the brackets that carry the brake lever and the parking stand. Steel tube 60.3 mm outside, 2.0 mm wall, with 4 and 5 mm steel plate brackets, S235 class.

**How to make it.**

1. Cut 370 mm of 60.3 x 2.0 mm tube, square. Mark a line along the top. All positions below are measured from the front end.
2. Check the bore with a 56.3 mm plug gauge or a bushing: it must slide end to end. File or hone out any seam bead.
3. Window: mark a 70 x 24 mm window on the right side, centred on the tube's side, from 105 to 175 mm. Chain drill and file it, and round its corners. The clevis pin goes in through it.
4. Flange: an 80 mm ring 6 mm thick with a 60.3 mm bore. Weld it flush on the rear end. Drill and tap four M5 holes on a 66 mm circle, 45 degrees either side of the top and bottom.
5. Fork: two 5 x 17 mm flat bars 112 mm long, welded on edge on top of the tube 12.8 mm apart (inside faces), 72 mm sticking out ahead of the tube's front end. Weld a 5 mm plate across their front ends to close the slot. The pin in the slot will rest 0.5 mm behind this plate.
6. Stand clevis: two 5 mm plates 30 x 31 mm, welded under the tube 25 mm apart, from 10 to 40 mm. Drill a 10.2 mm hole through both, 46 mm below the tube's centre line.
7. Lever cheeks: two 4 mm plates welded under the rear end, 16 mm apart, from 37 mm ahead of the rear end to 58 mm behind it, cut back to clear the flange. Drill an 8.2 mm pivot hole through both, 106 mm below the centre line and 23 mm behind the rear end.
8. Cable stop tab: a 5 x 24 mm plate across the cheeks' rear edges, with a 6 mm hole 120 mm below the centre line.
9. Clean the bore again after welding.

**How it fits the parts next to it.** The housing is welded into the frame's nose (section 3.4): the two nose bars meet its sides, 320 mm from its front end, and its centre line sits 356 mm above the ground, level with a bicycle's rear axle. The drawbar slides in its bore on two bushings, and the spring cage is bolted to its flange.

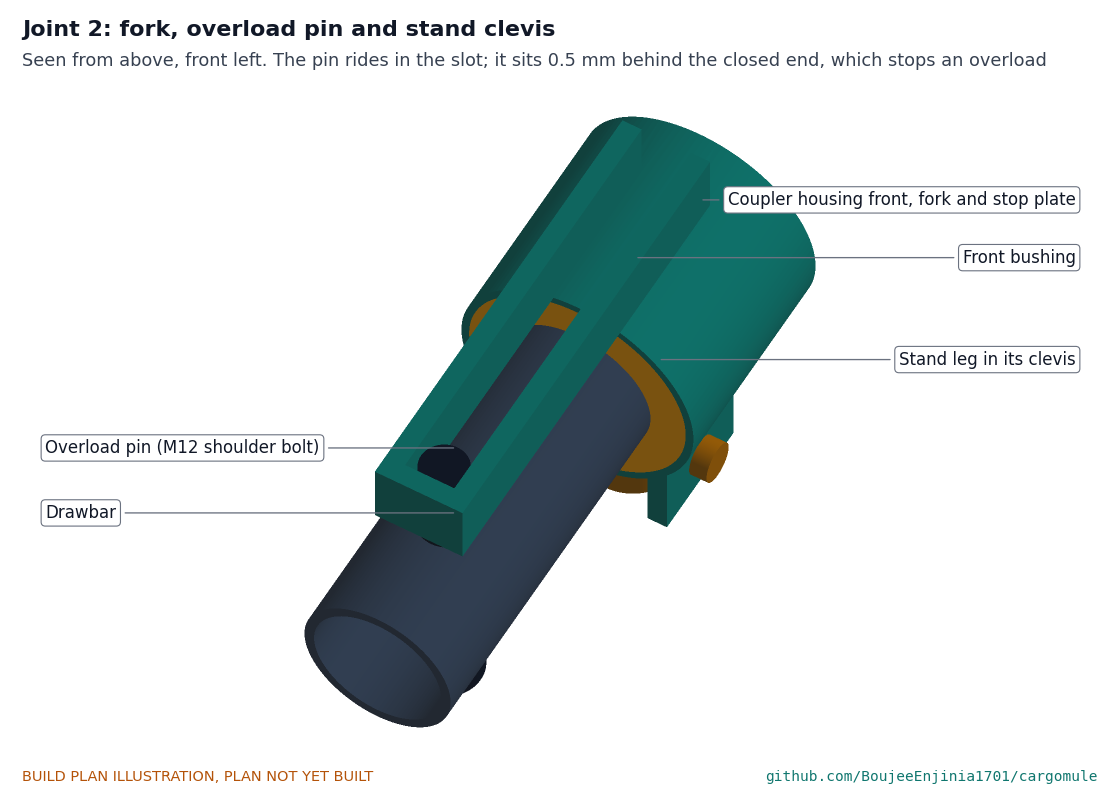
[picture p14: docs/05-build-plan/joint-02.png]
Figure 3. Joint 2: fork, overload pin and stand clevis


*Figure 3. The overload pin rides in the fork's slot so the drawbar cannot turn, and rests 0.5 mm behind the slot's closed front end so a pull beyond the load cell's range bears on the housing, not on the cell. The stand pivots in its clevis below.*

**Check before moving on.** A 38 mm bar 400 mm long slides through the tube with both bushings in, and the fork slot is square to the tube's top line.

### 3.2 Spring cage and end cap

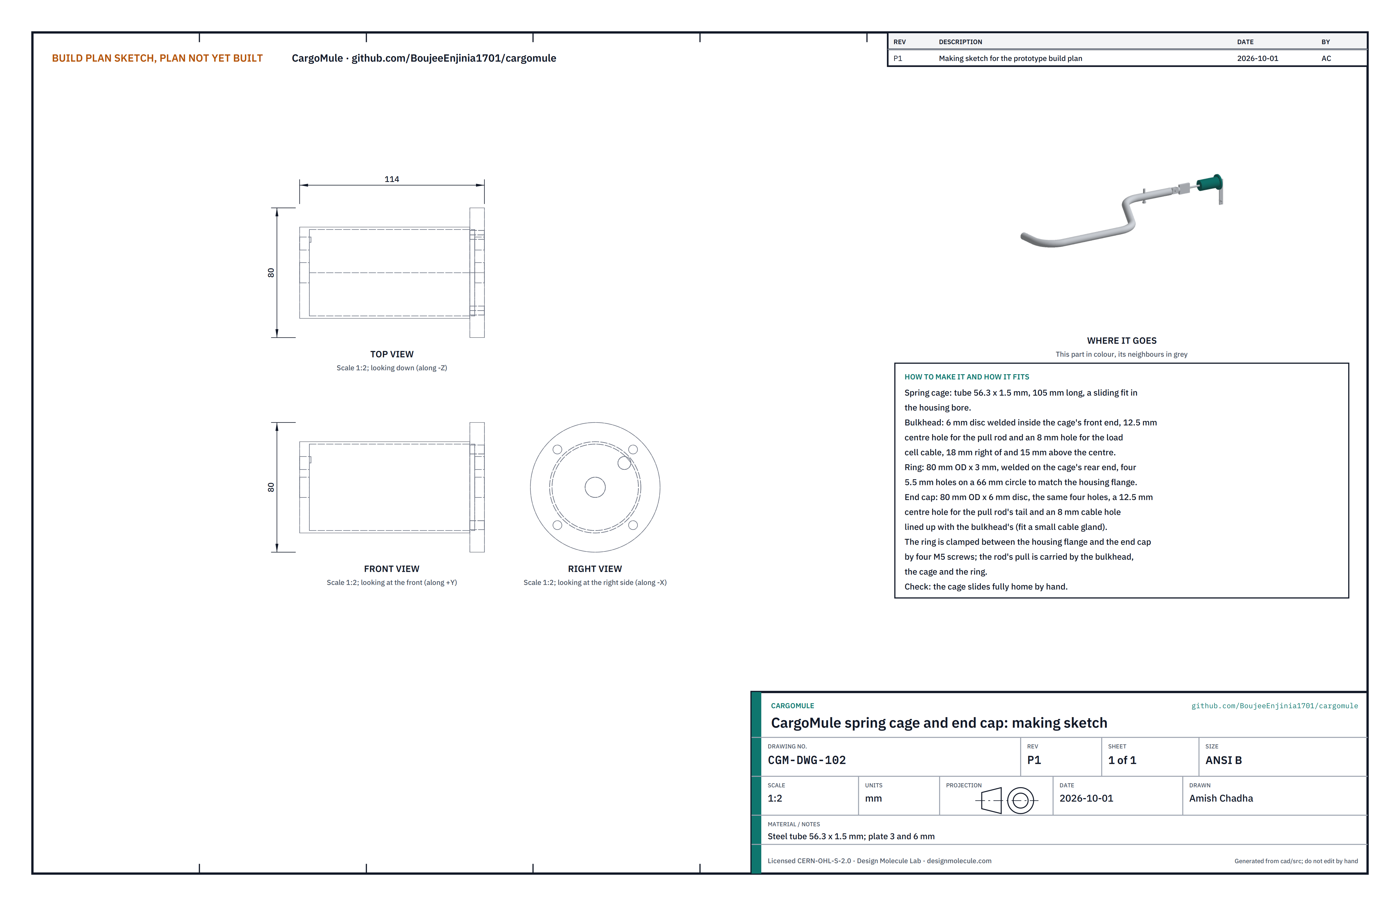
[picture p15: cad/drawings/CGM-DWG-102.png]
Figure 4. Making sketch of the spring cage and end cap


*Figure 4. Spring cage and end cap making sketch (CGM-DWG-102).*

**What it is and what it is made from.** A short tube that slides into the rear of the coupler housing and holds the spring, with a plate across its front end (the bulkhead) for the pull rod to pull on, and the bolted plate that closes the housing. Steel tube 56.3 x 1.5 mm and steel plate 3 and 6 mm.

**How to make it.**

1. Cut 105 mm of 56.3 x 1.5 mm tube. Check it slides into the housing's bore.
2. Bulkhead: a 6 mm disc that fits inside the tube, with a 12.5 mm centre hole and an 8 mm cable hole 18 mm right of and 15 mm above the centre. Weld it inside the tube's front end.
3. Ring: an 80 mm disc 3 mm thick with a 53.3 mm bore and four 5.5 mm holes on a 66 mm circle. Weld it on the tube's rear end.
4. End cap: an 80 mm disc 6 mm thick with the same four holes, a 12.5 mm centre hole and an 8 mm cable hole lined up with the bulkhead's. Fit a small cable gland in the cable hole.

**How it fits the parts next to it.** The cage slides into the housing until its ring meets the housing's flange; the end cap goes on behind the ring and four M5 screws clamp both to the flange (Figure 5). When the bicycle pulls, the pull rod's nut pulls the bulkhead forward, and the cage and ring carry that pull into the housing.

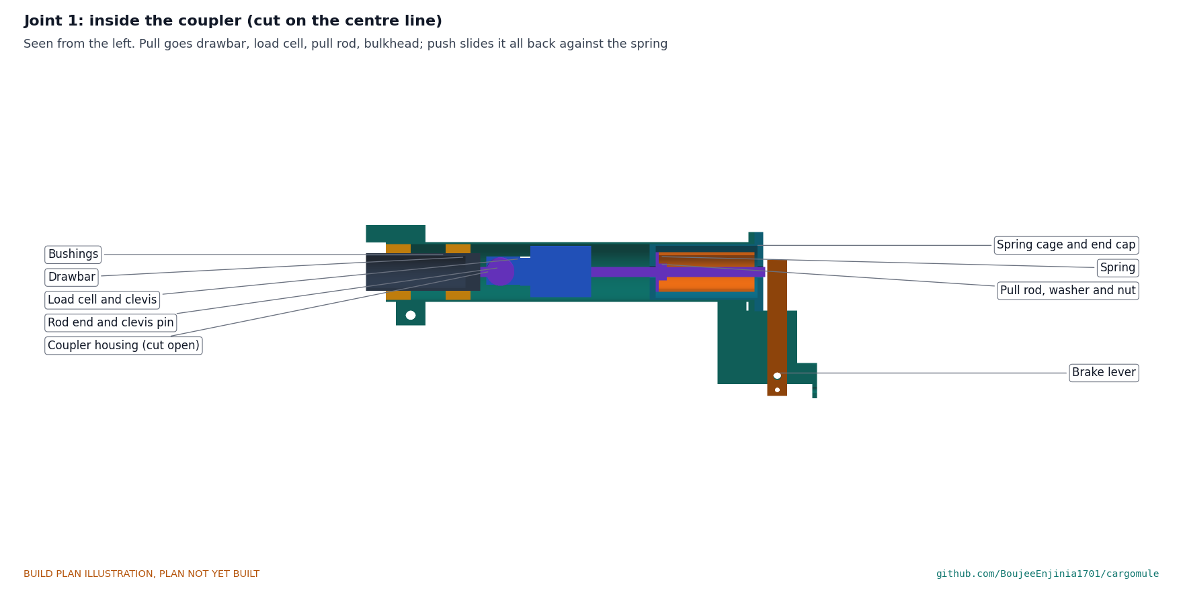
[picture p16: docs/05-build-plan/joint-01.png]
Figure 5. Joint 1: inside the coupler


*Figure 5. Inside the coupler, cut on the centre line. A pull goes from the drawbar through the rod end, clevis pin, load cell and pull rod to the nut on the cage's bulkhead. A push above 30 N slides the whole string back against the spring, and the rod's tail pushes the brake lever.*

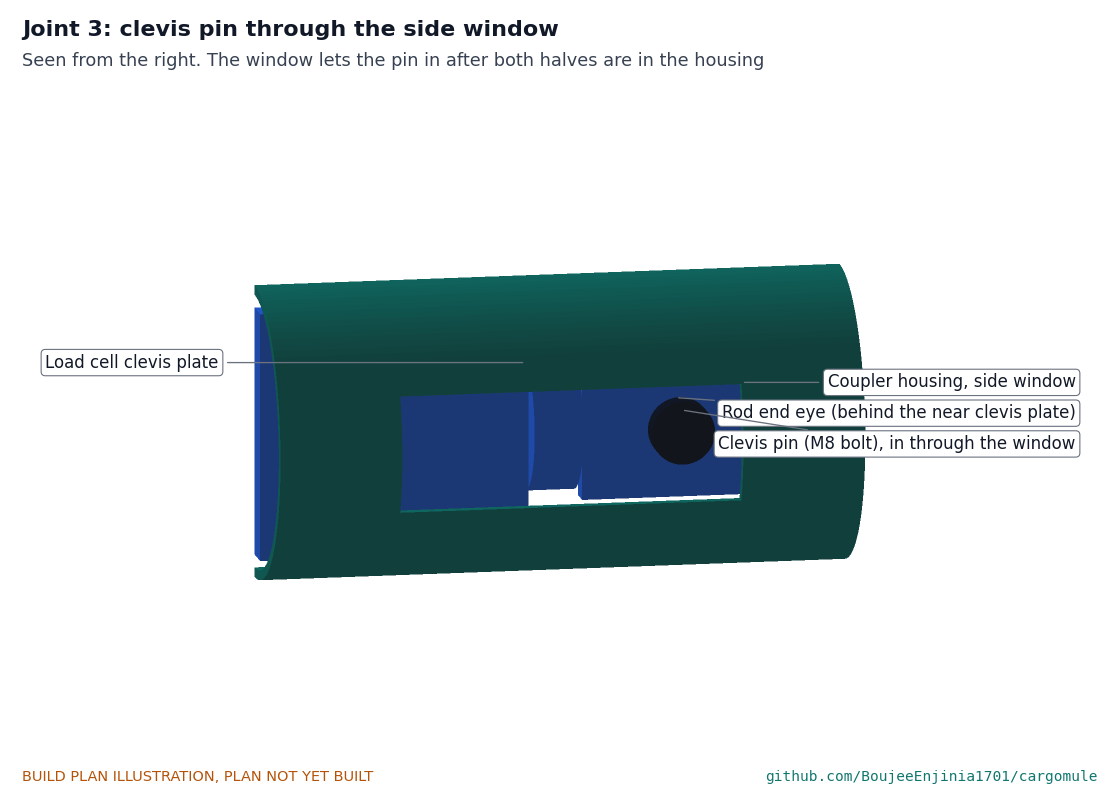
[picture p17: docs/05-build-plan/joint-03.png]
Figure 6. Joint 3: clevis pin through the side window


*Figure 6. Through the window in the housing's right side, the M8 clevis pin joins the rod end on the drawbar to the clevis on the load cell.*

**Check before moving on.** The cage slides fully home by hand, and the four holes line up with the flange's.

### 3.3 Dropout plates (make 4)

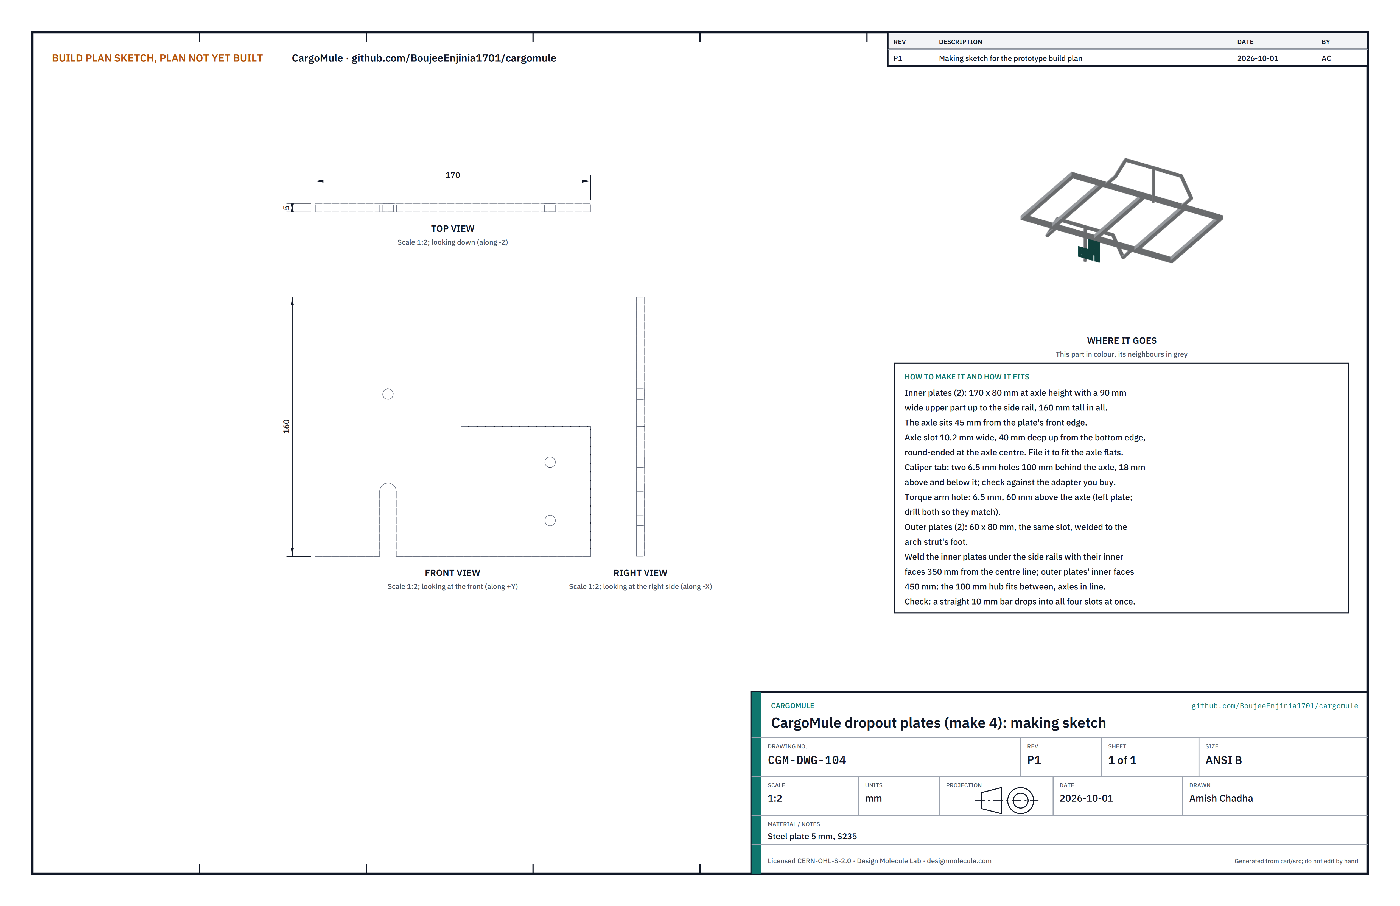
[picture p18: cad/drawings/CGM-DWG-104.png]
Figure 7. Making sketch of the dropout plates


*Figure 7. Dropout plate making sketch (CGM-DWG-104); the left inner plate is drawn.*

**What it is and what it is made from.** The plates that hold the wheel axles. Two inner plates hang under the side rails; two outer plates are welded to the arch frames outside the tyres. The inner plates also carry the brake calipers. Steel plate 5 mm.

**How to make it.**

1. Inner plates (2): cut a 170 x 80 mm piece with a 90 mm wide upper part on top, 160 mm tall in all. The axle centre is 45 mm from the front edge and 40 mm up from the bottom edge.
2. Cut the axle slot 10.2 mm wide from the bottom edge up to the axle centre, with a round end. Check it against the hub motor's axle flats and file it to a sliding fit.
3. Caliper tab: two 6.5 mm holes 100 mm behind the axle, 18 mm above and below it. Check the spacing against the caliper adapter you buy and move the holes to suit.
4. Torque arm hole: 6.5 mm, 60 mm above the axle, in both inner plates (only the left one is used).
5. Outer plates (2): 60 x 80 mm, axle 40 mm up from the bottom edge, the same slot.

**How it fits the parts next to it.** The inner plates' upper edges weld under the side rails with their inner faces 350 mm from the centre line; the outer plates weld to the feet of the arch frames' struts with their inner faces 450 mm from the centre line. The hub's 100 mm locknut faces then sit flat between them (Figures 8 and 9).

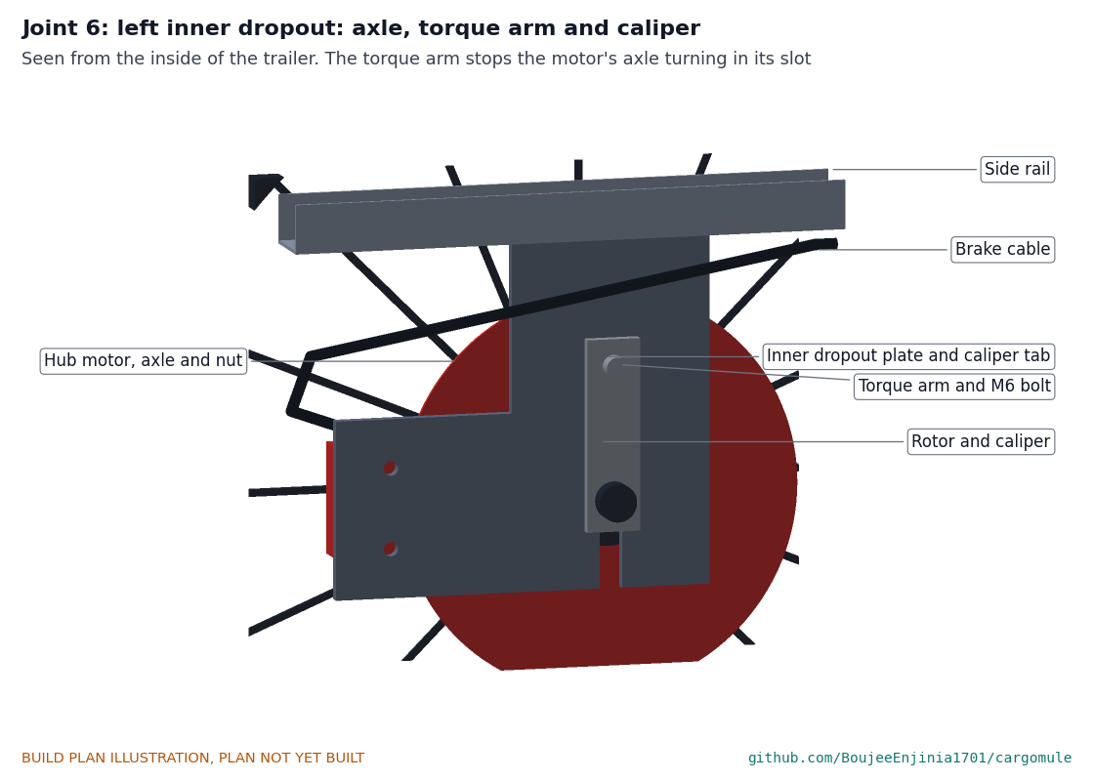
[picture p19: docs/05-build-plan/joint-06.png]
Figure 8. Joint 6: left inner dropout


*Figure 8. Left inner dropout from inside the trailer: the axle in its slot, the torque arm on the plate's inside face, and the caliper on its adapter on the tab.*

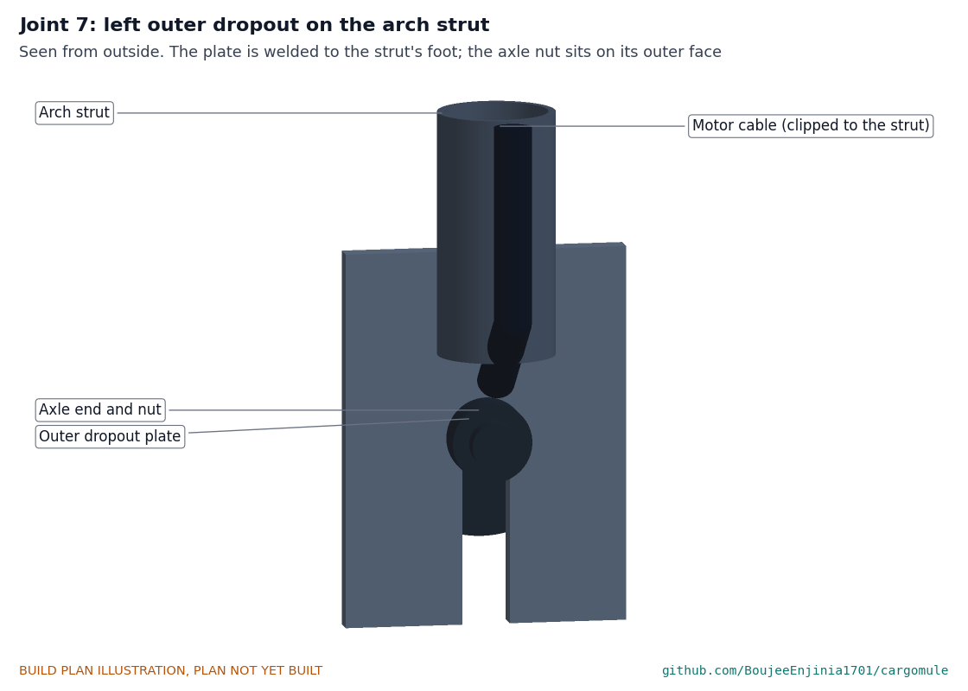
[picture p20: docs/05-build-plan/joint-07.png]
Figure 9. Joint 7: left outer dropout


*Figure 9. Left outer dropout on the arch strut's foot, with the axle nut on its outer face and the motor cable clipped up the strut.*

**Check before moving on.** After welding, a straight 10 mm bar drops into both slots of each wheel at once.

### 3.4 Chassis frame

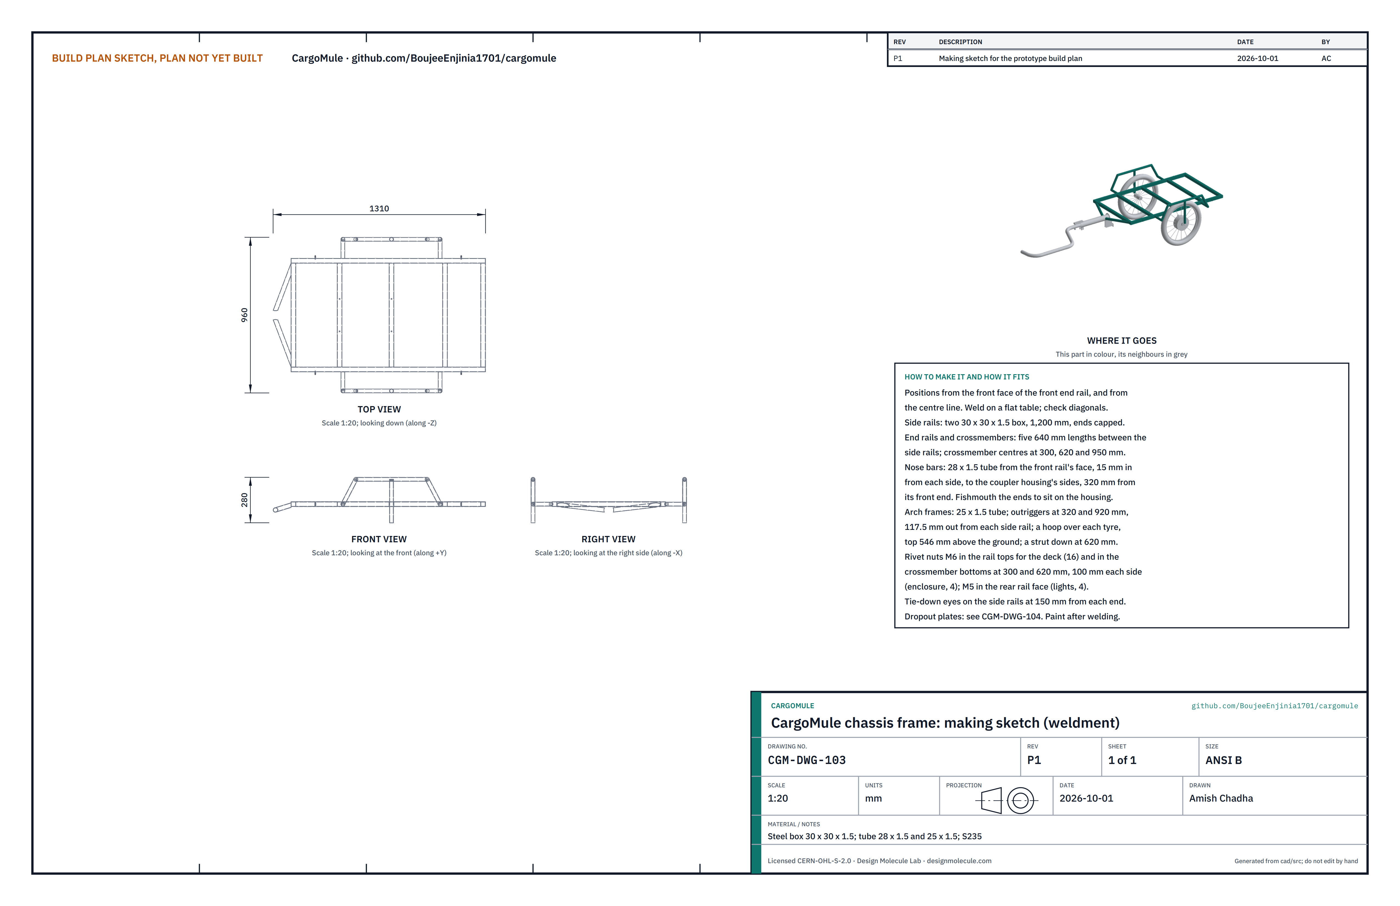
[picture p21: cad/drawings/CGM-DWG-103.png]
Figure 10. Making sketch of the chassis frame


*Figure 10. Chassis frame making sketch (CGM-DWG-103), without the dropout plates.*

**What it is and what it is made from.** The welded frame that everything hangs on: a rectangle of box section with three crossmembers, an A-shaped nose that carries the coupler housing, and an arch frame over each wheel that carries the outer dropout. Steel box section 30 x 30 x 1.5 mm, tube 28 x 1.5 mm and 25 x 1.5 mm, S235 class.

**How to make it.**

1. Cut two side rails 1,200 mm and five pieces 640 mm (the front and rear end rails and three crossmembers). Cap the side rails' open ends with welded plates.
2. On a flat welding table, lay out the rectangle 1,200 x 700 mm outside, with the crossmembers' centres 300, 620 and 950 mm from the front face. Tack, check both diagonals are equal within 2 mm, then weld.
3. Weld the coupler housing on the centre line, on packers: its rear end 50 mm ahead of the front rail's face, its centre line 22 mm below the rails' underside (356 mm above the ground when the trailer stands on its wheels).
4. Nose bars: two 28 x 1.5 mm tubes from the front rail's face, 15 mm in from each side and 15 mm above the rail's bottom, to the sides of the housing 320 mm from its front end. Fishmouth the housing ends to sit on the tube and weld all round.
5. Arch frames: for each side, two outriggers of 25 x 1.5 mm tube at 320 and 920 mm from the front, running out to 467.5 mm from the centre line; a hoop between them rising to 546 mm above the ground over the tyre; and a strut down from the hoop at 620 mm to the outer dropout plate.
6. Weld the dropout plates (section 3.3) with a straight 10 mm bar through all four slots to keep the axles in line.
7. Weld a tie-down eye to each side rail, 150 mm from each end.
8. Fit rivet nuts: 16 M6 in the rail tops for the deck (positions on the deck sketch, section 3.8), 4 M6 in the bottoms of the crossmembers at 300 and 620 mm, 100 mm each side of centre (enclosure), and 4 M5 in the rear rail's face (lights).
9. Grind the welds that face a part, deburr every edge, cap open tube ends and paint.

**How it fits the parts next to it.** The deck lies flat on the rail tops. The enclosure hangs from the two front crossmembers. The housing, nose bars and front rail form one welded nose:

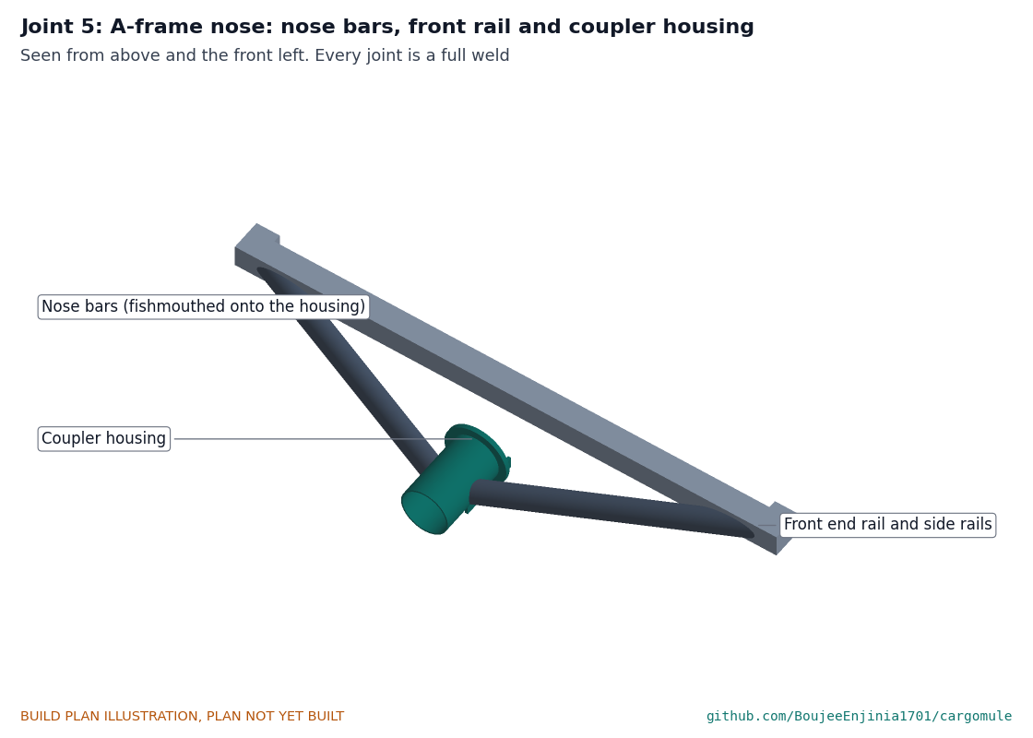
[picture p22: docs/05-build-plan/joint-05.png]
Figure 11. Joint 5: the A-frame nose


*Figure 11. The nose bars run from the front rail's face to the housing's sides; every joint is a full weld.*

**Check before moving on.** The frame sits flat on the table within 2 mm at all four corners; the diagonals agree within 2 mm; both wheels' slots line up on one axis.

### 3.5 Drawbar

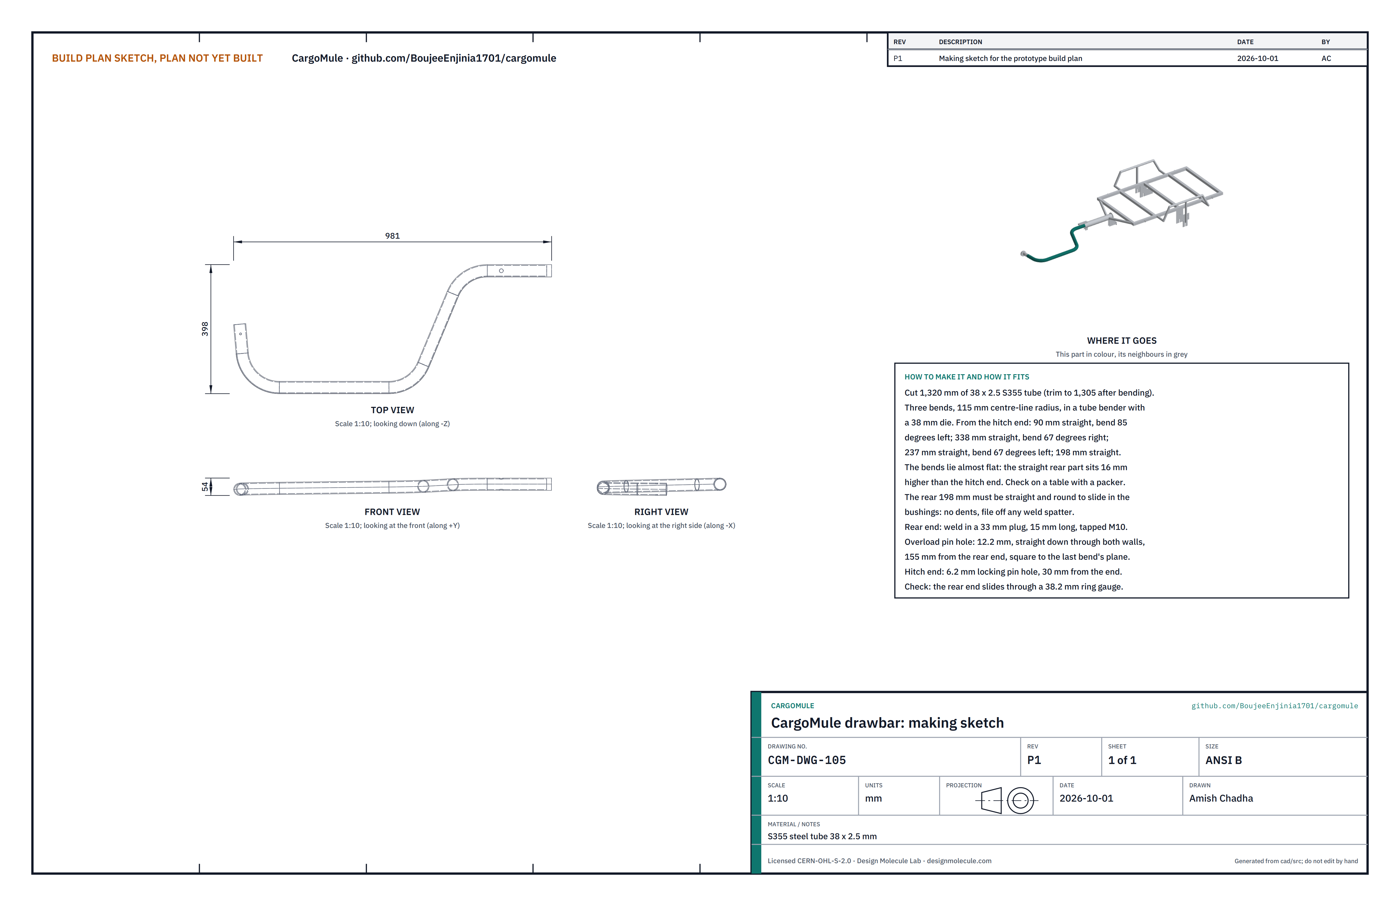
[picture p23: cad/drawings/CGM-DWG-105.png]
Figure 12. Making sketch of the drawbar


*Figure 12. Drawbar making sketch (CGM-DWG-105).*

**What it is and what it is made from.** The bent tube from the hitch on the bicycle to the coupler. It swings out to the left so it clears the bicycle's rear tyre in a turn, then runs straight down the trailer's centre line into the coupler housing. S355 steel tube 38 x 2.5 mm.

**How to make it.**

1. Cut 1,320 mm of tube. Mark the bend positions from the hitch end.
2. In a tube bender with a 38 mm die and 115 mm centre-line radius: 90 mm straight, bend 85 degrees; 338 mm straight, bend 67 degrees the same way; 237 mm straight, bend 67 degrees back the other way; 198 mm straight to the rear end. Lay it out on the floor to match the top view in Figure 12 before each bend.
3. The three bends lie almost flat. The straight rear part sits 16 mm higher than the hitch end: check on a flat table with a 16 mm packer under the rear part.
4. Trim the rear end square, to 1,305 mm along the centre line in all.
5. Weld a 33 mm steel plug, 15 mm long and tapped M10, flush into the rear end.
6. Overload pin hole: 12.2 mm, straight down through both walls, 155 mm from the rear end, square to the plane of the last bend.
7. Hitch end: a 6.2 mm hole straight down through both walls, 30 mm from the end, for the hitch's locking pin.
8. Dress the straight rear part: it must be round and clean to slide in the bushings, with no dents or spatter.

**How it fits the parts next to it.** The straight rear part slides in the coupler housing's bushings. A rod end screws into its plug, and the overload pin goes through its hole and rides in the fork's slot (Figures 5 and 3). The hitch's arm slides 60 mm into its front end:

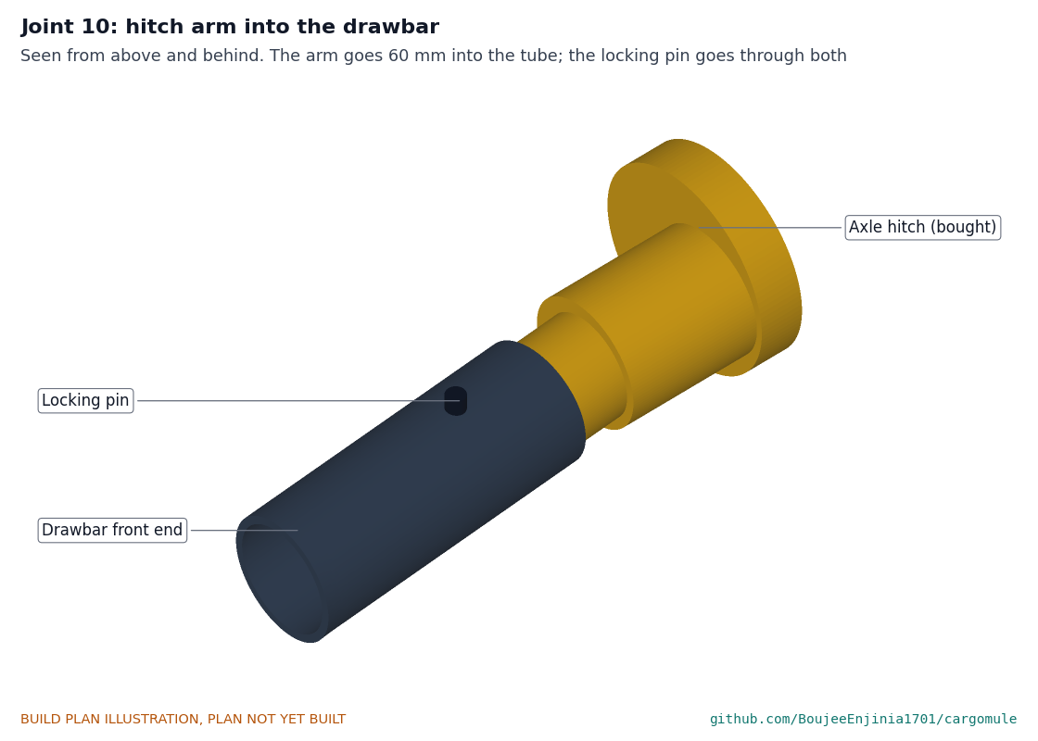
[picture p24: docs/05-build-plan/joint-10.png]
Figure 13. Joint 10: hitch arm into the drawbar


*Figure 13. The hitch's arm goes 60 mm into the drawbar; the locking pin goes through both.*

**Check before moving on.** The rear end passes through a 38.2 mm ring gauge along its whole straight length, and the bends match the drawing on a flat table.

### 3.6 Brake lever

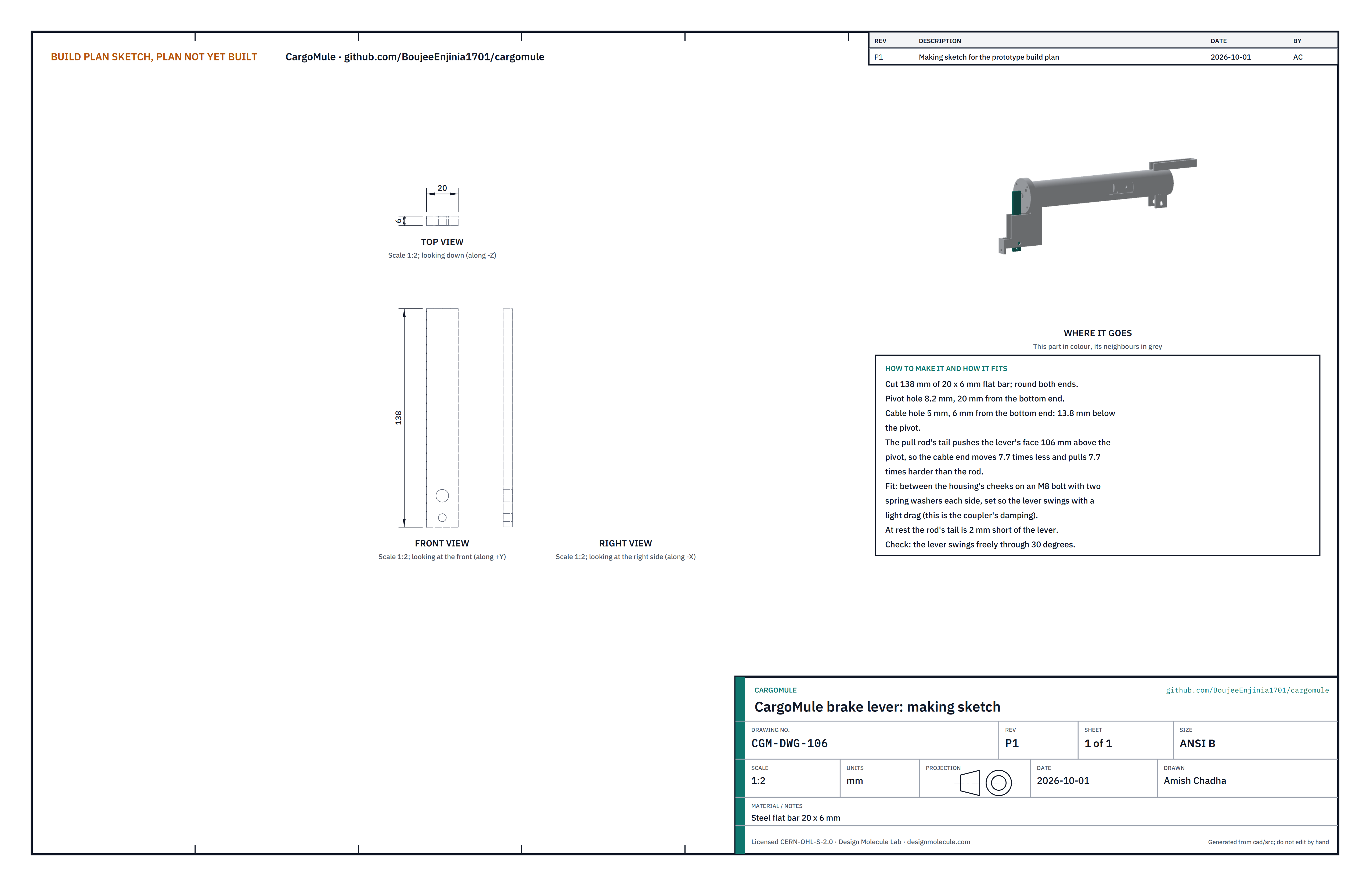
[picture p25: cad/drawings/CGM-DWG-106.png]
Figure 14. Making sketch of the brake lever


*Figure 14. Brake lever making sketch (CGM-DWG-106).*

**What it is and what it is made from.** The lever that turns the coupler's slide into a pull on the brake cables, 7.7 times harder and 7.7 times shorter. Steel flat bar 20 x 6 mm.

**How to make it.**

1. Cut 138 mm of 20 x 6 mm flat bar and round both ends.
2. Drill the pivot hole 8.2 mm, 20 mm from the bottom end.
3. Drill the cable hole 5 mm, 6 mm from the bottom end (13.8 mm below the pivot).
4. Deburr.

**How it fits the parts next to it.** The lever hangs between the housing's cheeks on an M8 bolt with two spring washers each side, set so it swings with a light drag; that drag is the coupler's damping. The pull rod's tail stops 2 mm short of the lever's face, 106 mm above the pivot. The brake cable's inner wire is clamped in the cable hole and runs back through the stop tab (Figure 15).

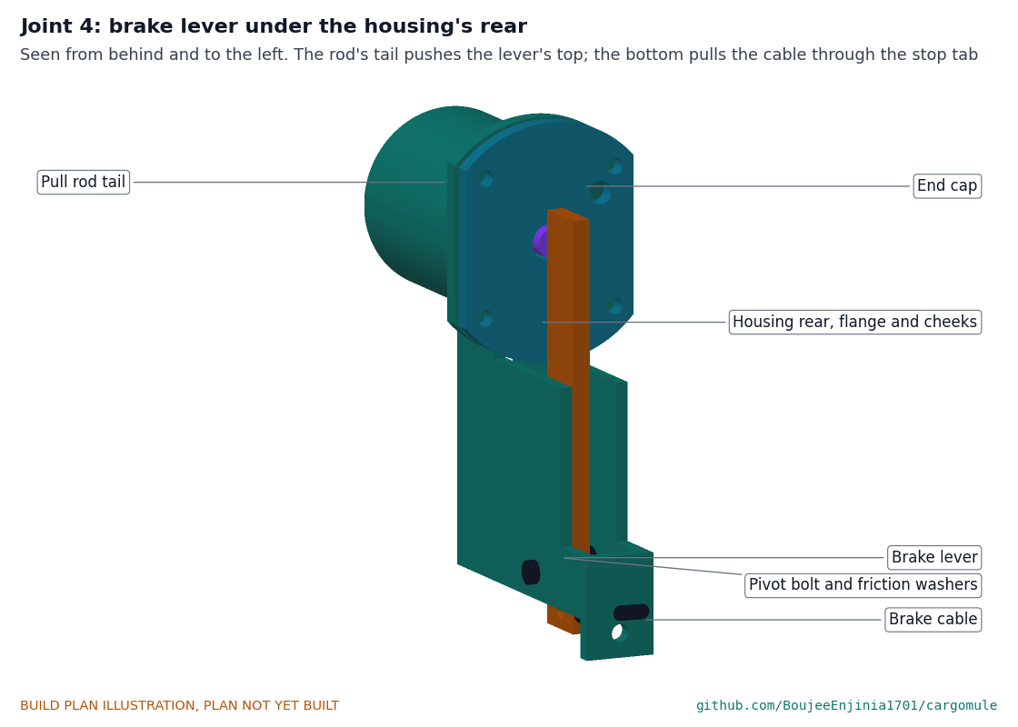
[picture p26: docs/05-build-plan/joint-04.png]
Figure 15. Joint 4: brake lever


*Figure 15. The rod's tail pushes the lever's top rearward; its bottom pulls the brake cable forward through the stop tab.*

**Check before moving on.** The lever swings freely through 30 degrees on its bolt with a steady light drag.

### 3.7 Parking stand

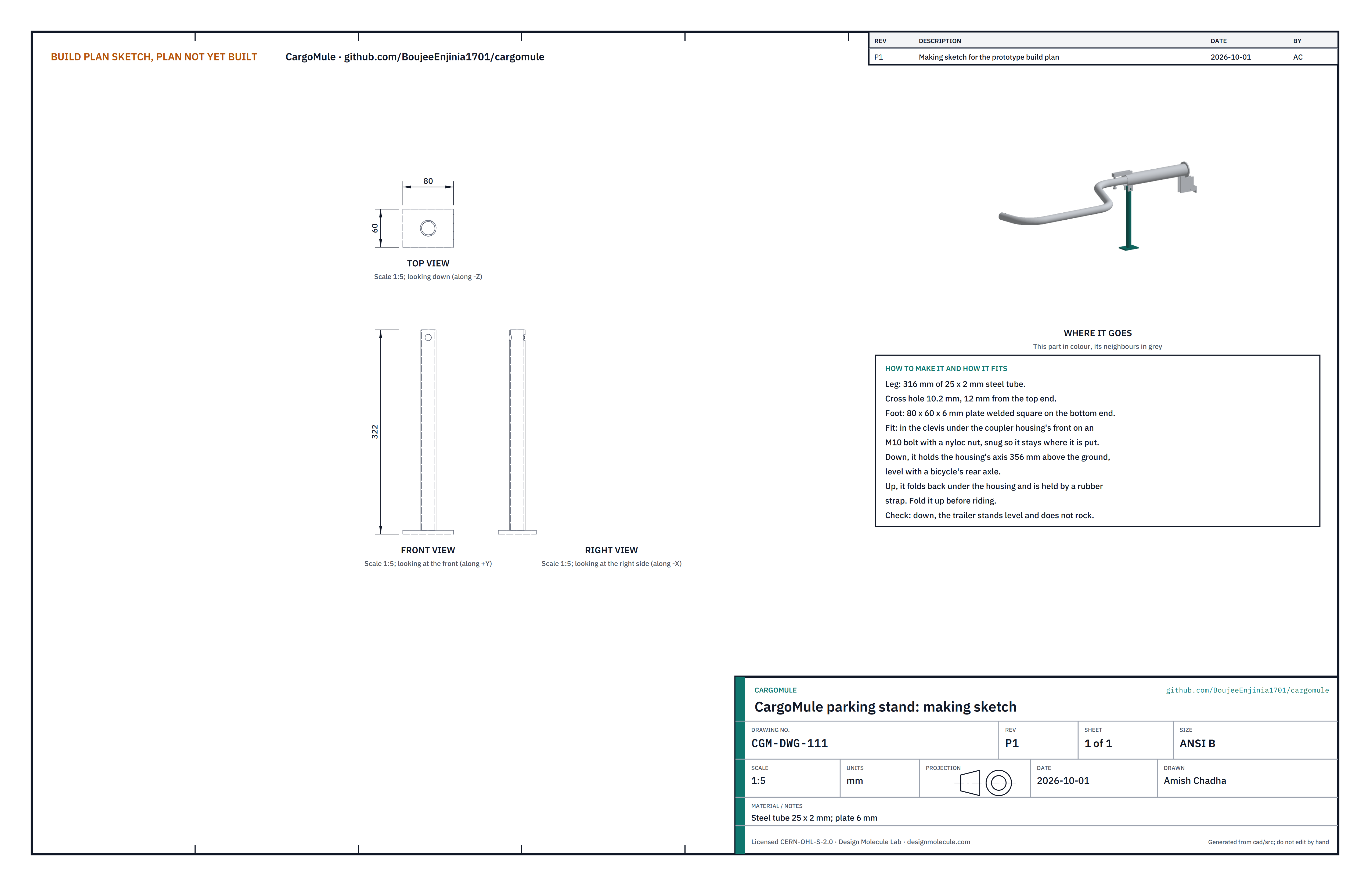
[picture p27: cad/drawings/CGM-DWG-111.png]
Figure 16. Making sketch of the parking stand


*Figure 16. Parking stand making sketch (CGM-DWG-111).*

**What it is and what it is made from.** A leg that holds the coupler level when the trailer is unhitched. Steel tube 25 x 2 mm and a 6 mm foot plate.

**How to make it.**

1. Cut 316 mm of 25 x 2 mm tube.
2. Drill a 10.2 mm cross hole 12 mm from the top end.
3. Weld an 80 x 60 x 6 mm foot plate square on the bottom end.

**How it fits the parts next to it.** The leg pivots in the clevis under the housing's front on an M10 bolt with a nyloc nut, snug enough to stay where it is put (Figure 3). Down, it holds the housing's centre line 356 mm above the ground. Up, it folds back under the housing and a rubber strap holds it.

**Check before moving on.** With the stand down, the trailer stands level and does not rock.

### 3.8 Deck

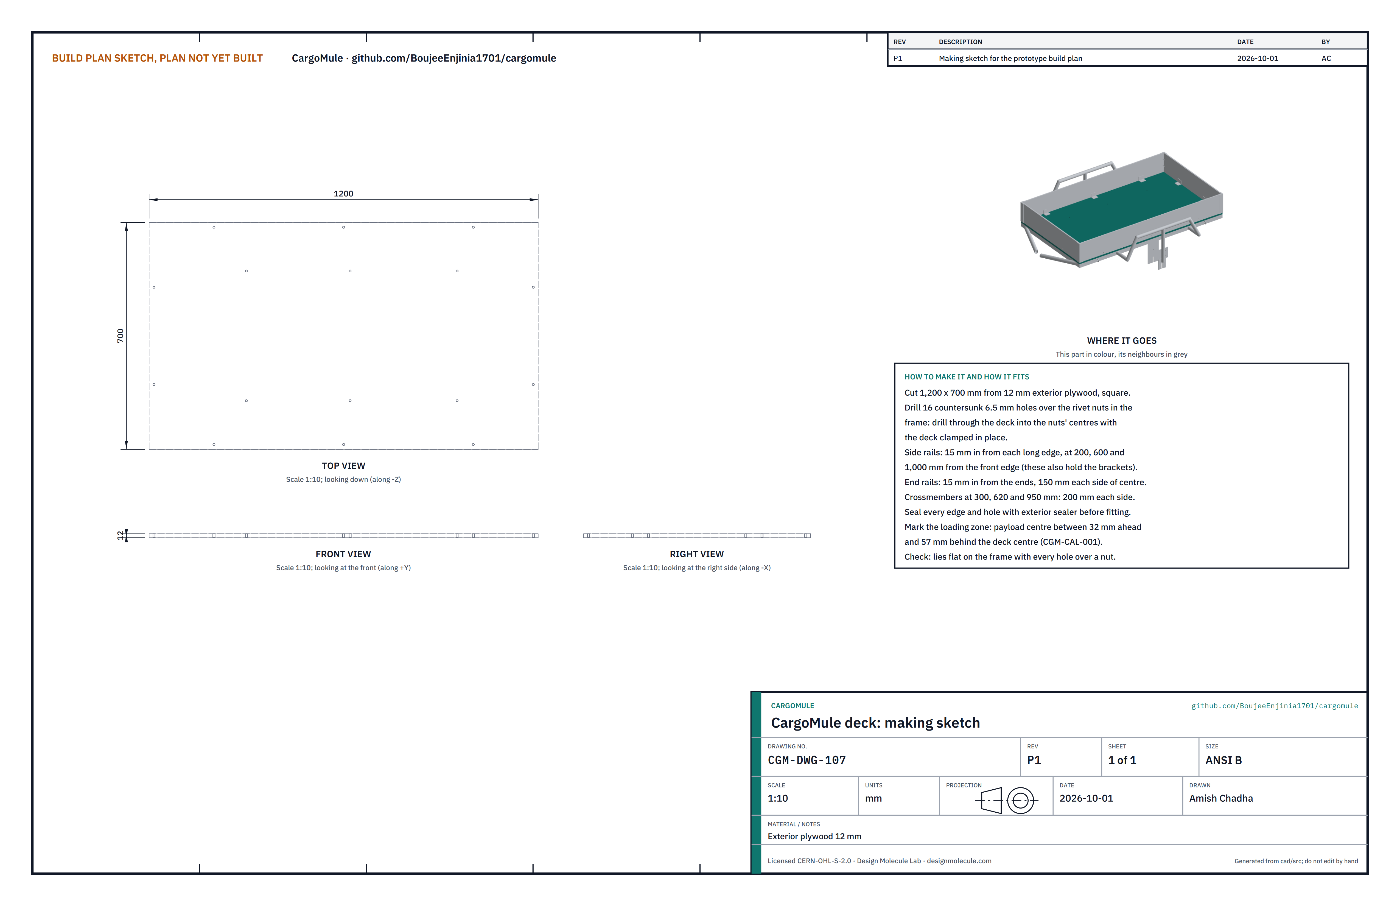
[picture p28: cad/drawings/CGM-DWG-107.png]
Figure 17. Making sketch of the deck


*Figure 17. Deck making sketch (CGM-DWG-107).*

**What it is and what it is made from.** The floor of the load space. Exterior plywood 12 mm.

**How to make it.**

1. Cut 1,200 x 700 mm, square.
2. Clamp it on the frame, flush at the front and both sides, and drill 6.5 mm through it into the centre of each rivet nut: on the side rails 15 mm in from each long edge at 200, 600 and 1,000 mm from the front; on the end rails 15 mm in from each end, 150 mm each side of centre; on the crossmembers at 300, 620 and 950 mm, 200 mm each side of centre. Countersink every hole.
3. Seal every edge and hole with exterior sealer.
4. Paint a loading zone on the top: the load's centre must sit between 32 mm ahead of and 57 mm behind the deck's centre.

**How it fits the parts next to it.** The deck lies flat on the frame's top and is held by 16 M6 countersunk bolts into the rivet nuts. The board brackets share the bolts at the edges (Figure 20).

**Check before moving on.** The deck lies flat with every hole over a rivet nut.

### 3.9 Side and end boards, corner pieces and brackets

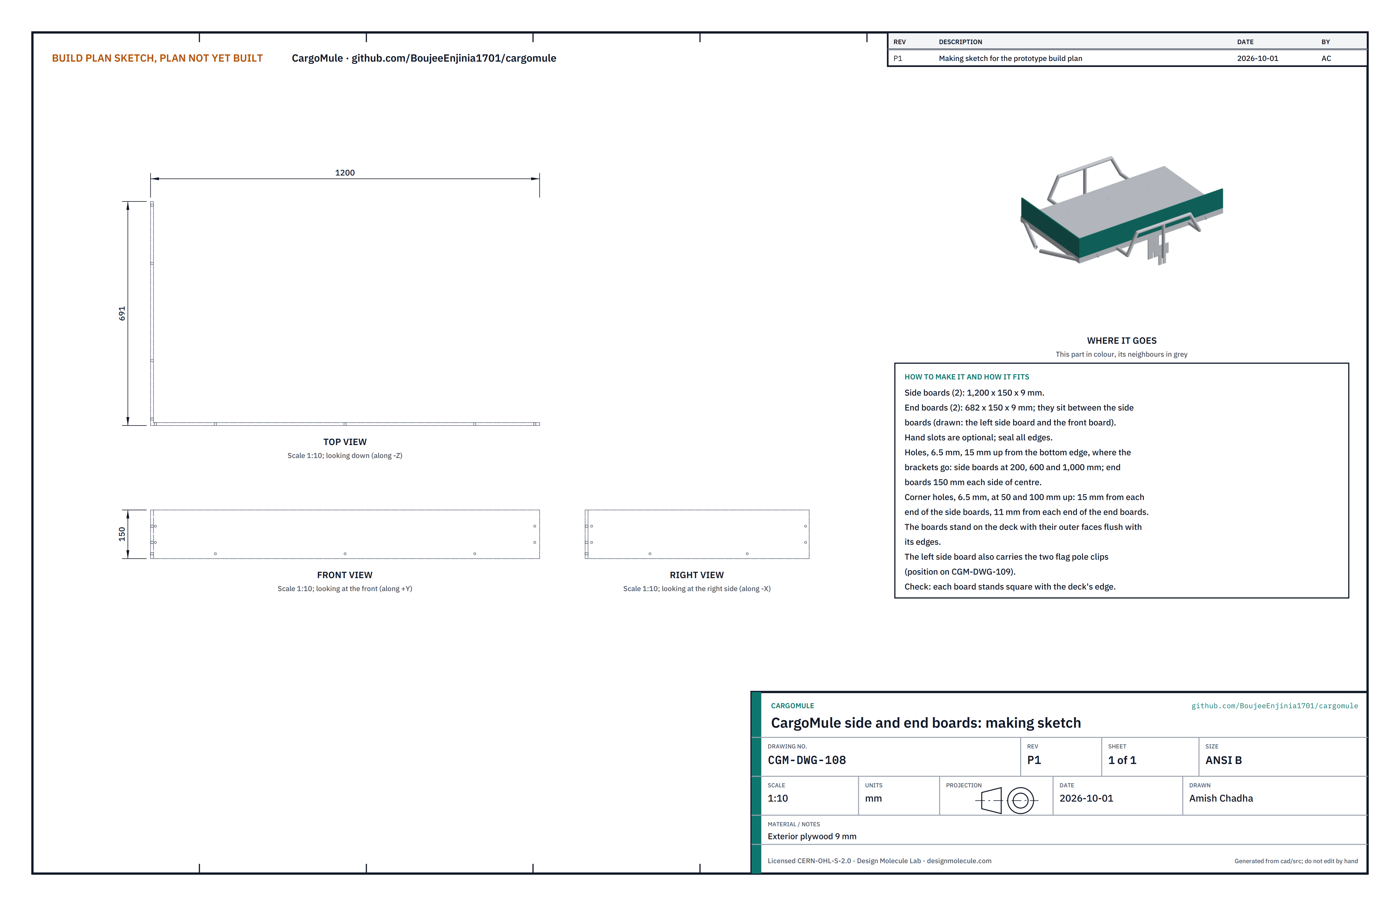
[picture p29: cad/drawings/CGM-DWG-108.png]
Figure 18. Making sketch of the side and end boards


*Figure 18. Side and end boards making sketch (CGM-DWG-108).*

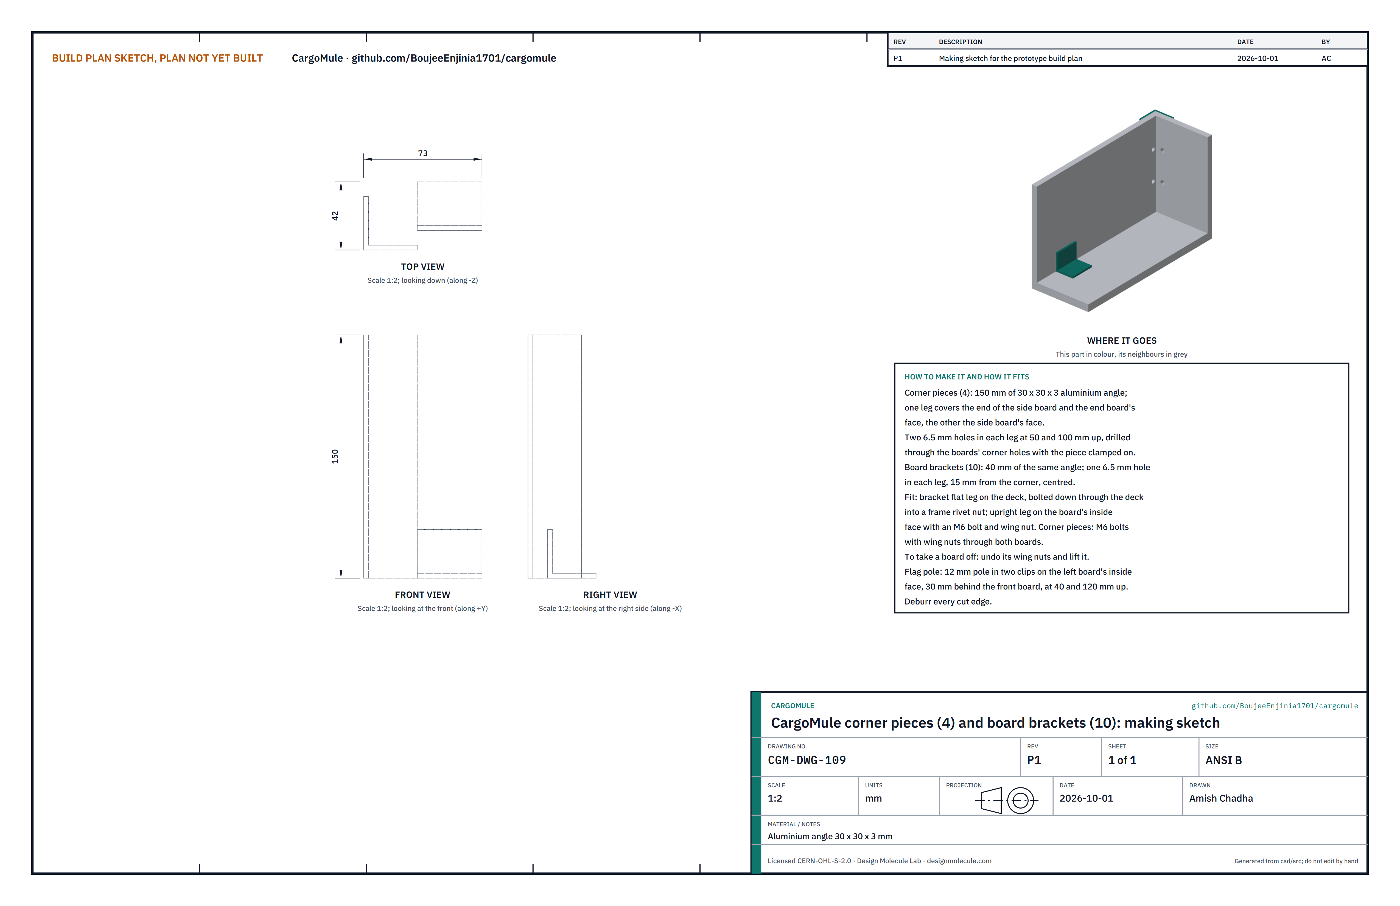
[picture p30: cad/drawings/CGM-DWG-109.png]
Figure 19. Making sketch of the corner pieces and brackets


*Figure 19. Corner piece and board bracket making sketch (CGM-DWG-109).*

**What they are and what they are made from.** Four removable boards 150 mm high round the deck, held by aluminium angle corner pieces and brackets. Exterior plywood 9 mm; aluminium angle 30 x 30 x 3 mm.

**How to make them.**

1. Side boards (2): 1,200 x 150 mm. End boards (2): 682 x 150 mm. Seal all edges.
2. Bracket holes, 6.5 mm, 15 mm up from the bottom edge: side boards at 200, 600 and 1,000 mm from the front end; end boards 150 mm each side of centre.
3. Corner holes, 6.5 mm, at 50 and 100 mm up: 15 mm from each end of the side boards, 11 mm from each end of the end boards.
4. Corner pieces (4): 150 mm of angle; clamp each on its corner and drill two 6.5 mm holes in each leg through the boards' corner holes.
5. Brackets (10): 40 mm of angle, one 6.5 mm hole in each leg, 15 mm from the corner, centred.
6. Deburr every cut.

**How they fit the parts next to them.** The boards stand on the deck with their outer faces flush with its edges. Each bracket's flat leg is bolted down through the deck into a rivet nut, and its upright leg holds the board with an M6 bolt and a wing nut on the inside. Each corner piece wraps the corner outside and is bolted through both boards with wing nuts. The flag pole sits in two clips on the left board's inside face, 30 mm behind the front board, at 40 and 120 mm above the deck.

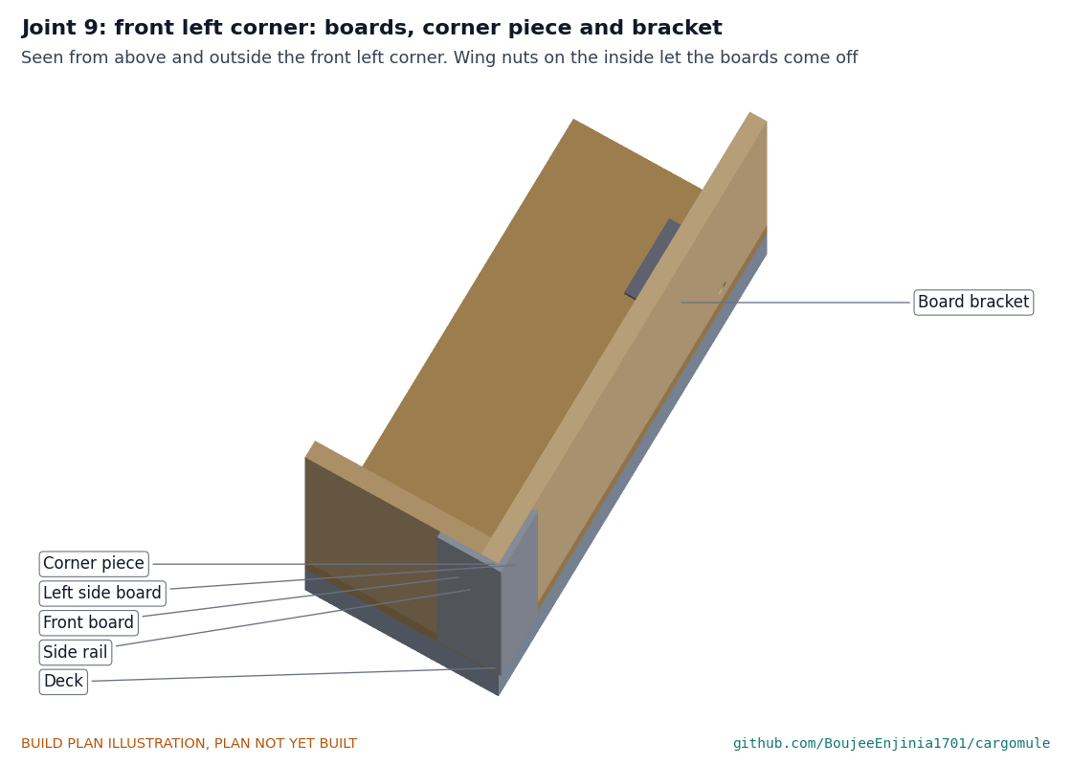
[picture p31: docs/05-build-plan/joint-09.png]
Figure 20. Joint 9: front left corner of the load space


*Figure 20. Boards, corner piece and bracket at the front left corner.*

**Check before moving on.** Each board stands square to the deck edge, and every wing nut can be reached from inside the load space.

### 3.10 Battery enclosure and door

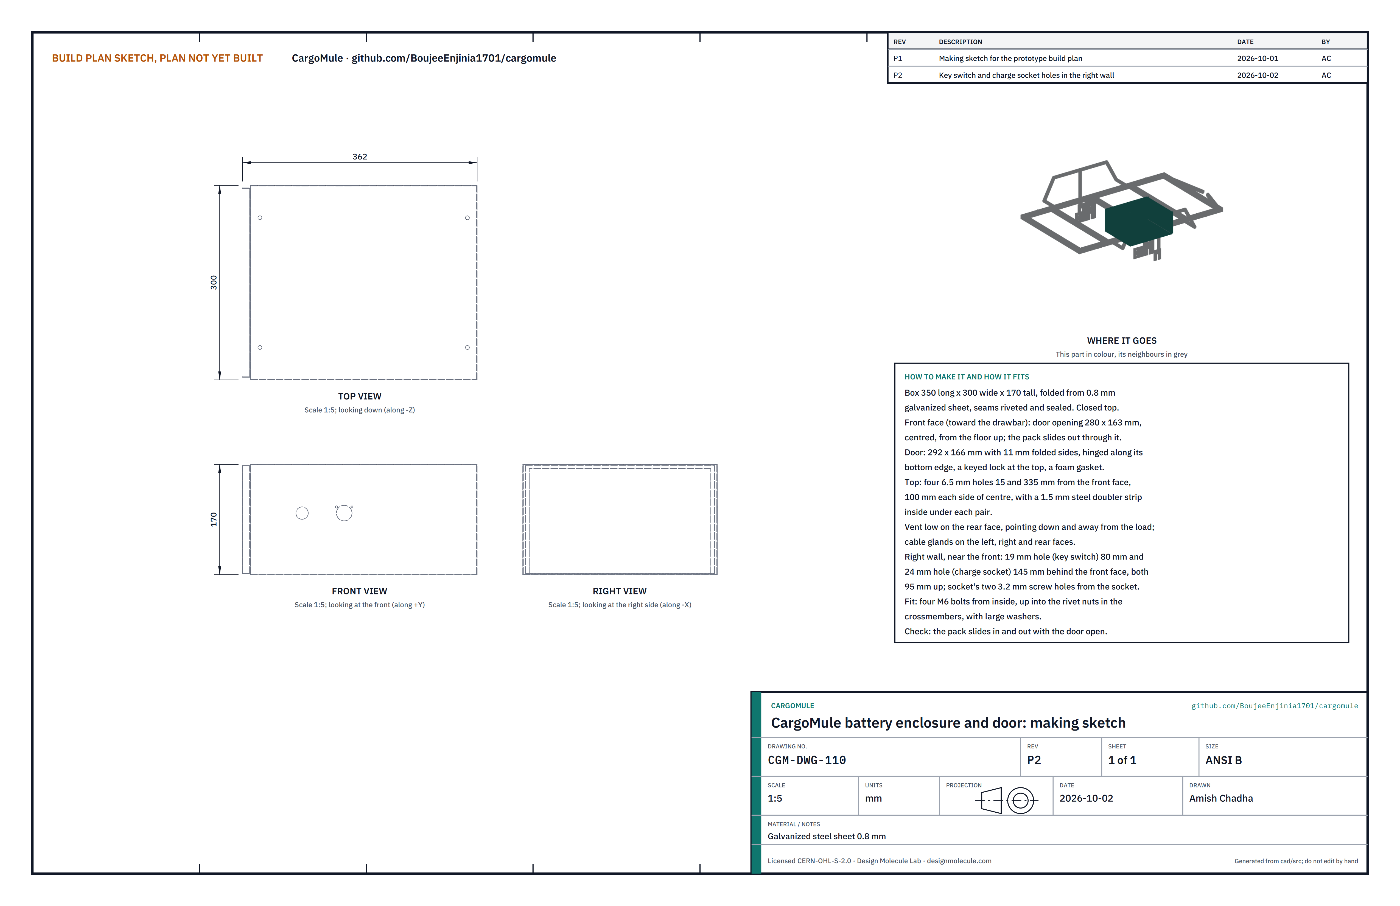
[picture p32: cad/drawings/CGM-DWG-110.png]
Figure 21. Making sketch of the enclosure


*Figure 21. Battery enclosure and door making sketch (CGM-DWG-110).*

**What it is and what it is made from.** A closed steel box under the front of the deck for the battery pack, motor controller and control board, with a lockable door on its front face and the key switch and charge socket in its right wall near the front. Galvanized steel sheet 0.8 mm.

**How to make it.**

1. Fold the box 350 long x 300 wide x 170 mm tall from 0.8 mm sheet, with a closed top and bottom. Rivet and seal the seams.
2. Front face (toward the drawbar): cut a 280 x 163 mm door opening, centred, from the floor up.
3. Door: 292 x 166 mm with 11 mm folded sides; hinge it along its bottom edge; fit a keyed lock at its top and a foam gasket round the opening.
4. Top: four 6.5 mm holes, 15 and 335 mm from the front face, 100 mm each side of centre. Rivet a 1.5 mm steel doubler strip inside under each pair.
5. Fit a vent low on the rear face, pointing down and away from the load, and cable glands in the left wall (motor cable), right wall (load cell cable, 40 mm behind the front face) and rear wall (light cables).
6. Right wall, near the front: drill or punch a 19 mm hole for the key switch, centred 80 mm behind the front face and 95 mm up from the bottom, and a 24 mm hole for the charge socket, centred 145 mm behind the front face at the same height. Mark the socket's two small flange screw holes from the socket itself (3.2 mm, about 24 mm apart, above the hole) and drill them. Deburr every hole and touch up the zinc on the cut edges. Keeping both on this wall means no lead has to bend across the door's hinge.

**How it fits the parts next to it.** The box's top sits flat under the crossmembers at 300 and 620 mm from the frame's front, held by four M6 bolts from inside into the rivet nuts, with large washers (Figure 22). The controller and control board are screwed to its floor on the right; the pack sits on a rubber mat on the left and is strapped down; it slides out forward through the door, under the deck. The key switch and charge socket are reached from the right side of the trailer, under the deck's edge.

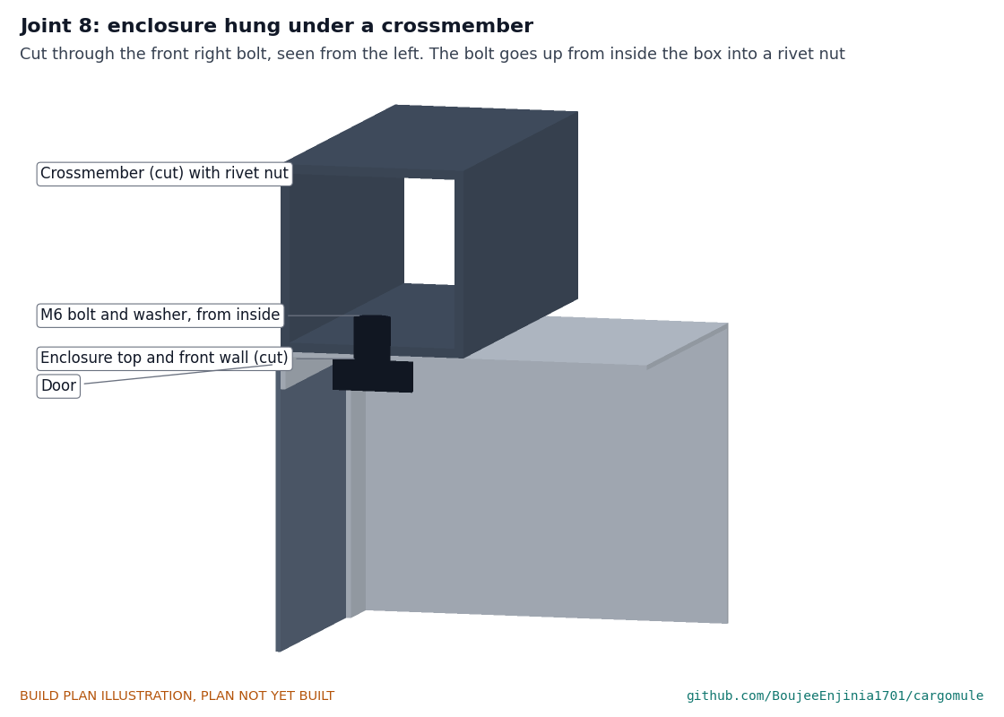
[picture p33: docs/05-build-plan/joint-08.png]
Figure 22. Joint 8: enclosure under a crossmember


*Figure 22. Cut through the front right enclosure bolt: the bolt goes up from inside the box into a rivet nut in the crossmember.*

**Check before moving on.** The door closes and locks over its gasket; an empty pack case slides in and out through the door; the key switch and charge socket fit their holes with their seals flat on the wall.

### 3.11 Bought components and what to do to them

Buy to specification, not brand. Line numbers are those of the bill of materials.

- **Axle hitch (line 4).** Clamps under the bicycle's left rear axle end (9 mm quick release or 12 mm thru-axle with the matching hitch axle), a joint that allows pitch, yaw and roll, a 32 mm arm with a 6 mm locking pin and a visible lock indicator, and a safety strap rated 3.9 kN or more.
- **Load cell (line 5).** S-type, 1 kN, 2 mV/V, IP66, M10 threads at both ends, no more than 54 mm across its diagonal; an M10 rod end with a spherical eye; a clevis that screws onto the cell with an M8 pin; an HX711-class amplifier, potted in the enclosure.
- **Coupler parts (line 6).** Two acetal bushings 38 mm bore, 56.3 mm outside, 25 mm long (or turn them from 60 mm acetal rod); an M10 pull rod about 180 mm long with a 40 mm spring seat washer and nut; a compression spring about 40 mm outside, 96 mm free length, giving about 30 N where fitted and under 40 mm solid; an M12 shoulder bolt with a nyloc nut for the overload pin; a brake cable splitter (one in, two out) and three brake cables.
- **Hub motor wheel (line 7).** 36 V 250 W geared front-style hub, 100 mm spacing, disc mount, 10 mm axle flats, cable exit on the non-disc side, laced in a 20 in rim; a torque arm to suit.
- **Idler wheel (line 8).** 20 in wheel with a 100 mm disc hub.
- **Disc brakes (line 9).** Two cable calipers with 180 mm rotors, metallic pads and post-mount adapters. Fit each rotor on its hub at the bench with its six screws and threadlocker, with the rotor on the side that faces the trailer's centre.
- **Pack, controller, board, harness (lines 11 to 14).** As the bill of materials. The harness has keyed waterproof connectors, so the pack and each cable unplug. Line 14 also has a keyed on-off switch for a 19 mm panel hole and a 3-pin charge socket with a hinged cap for a 24 mm panel hole; check that the socket mates with the charger's plug before drilling.
- **Lights, reflectors and flag (line 15).** Two rear lights, side reflectors, an amber drawbar reflector about 100 x 24 mm with two stainless hose clips, a 12 mm flag pole and two pole clips.
- **Fixings (line 18).** 20 M6 and 4 M5 rivet nuts; M6 countersunk bolts for the deck; M6 bolts and wing nuts for the boards; M5 screws for the end cap and lights; M8 and M10 bolts with nyloc nuts for the lever, clevis pin and stand; cable clips and ties.

## 4. Putting it together

In each picture the parts already fitted are grey and the parts being fitted are in colour, with an arrow showing the way they go in. Work with the frame on two trestles about 500 mm high until step 12.

### Step 1: bushings into the coupler housing

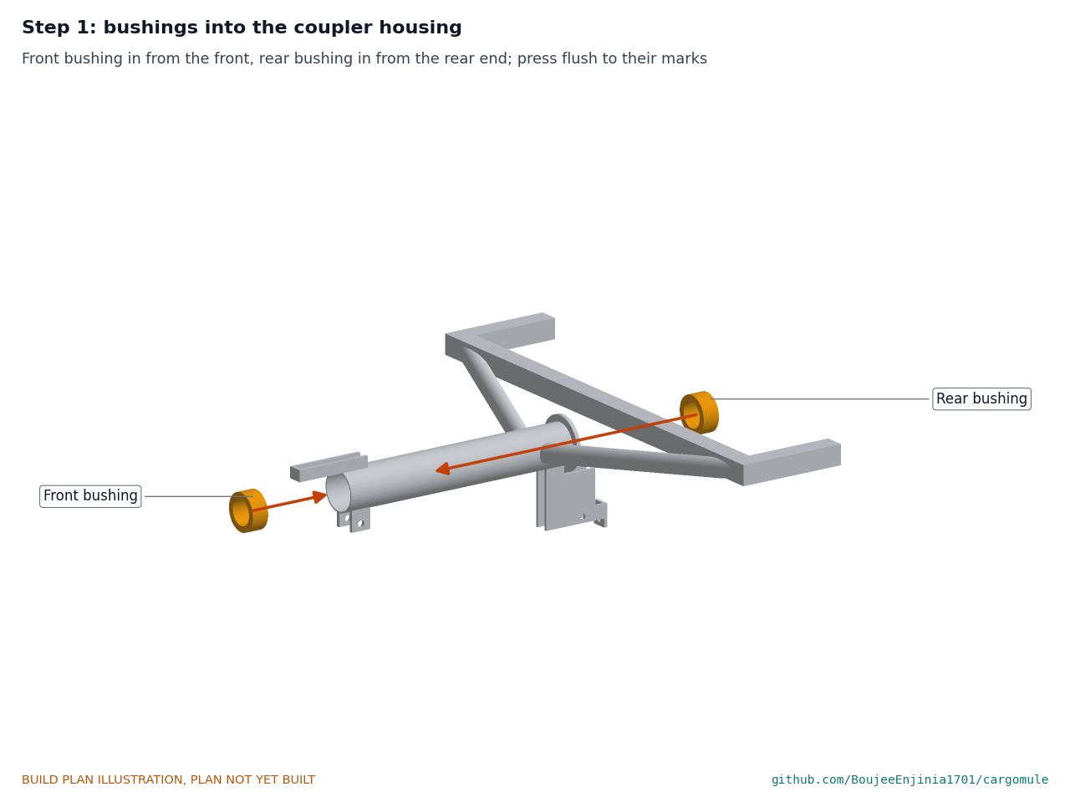
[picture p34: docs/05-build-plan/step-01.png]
Step 1


Press the front bushing into the housing's front end until flush, and the rear bushing in from the rear end until it sits 60 to 85 mm from the front end (mark the depth on a rod). A light smear of grease on the bore.

### Step 2: drawbar in from the front, then the overload pin

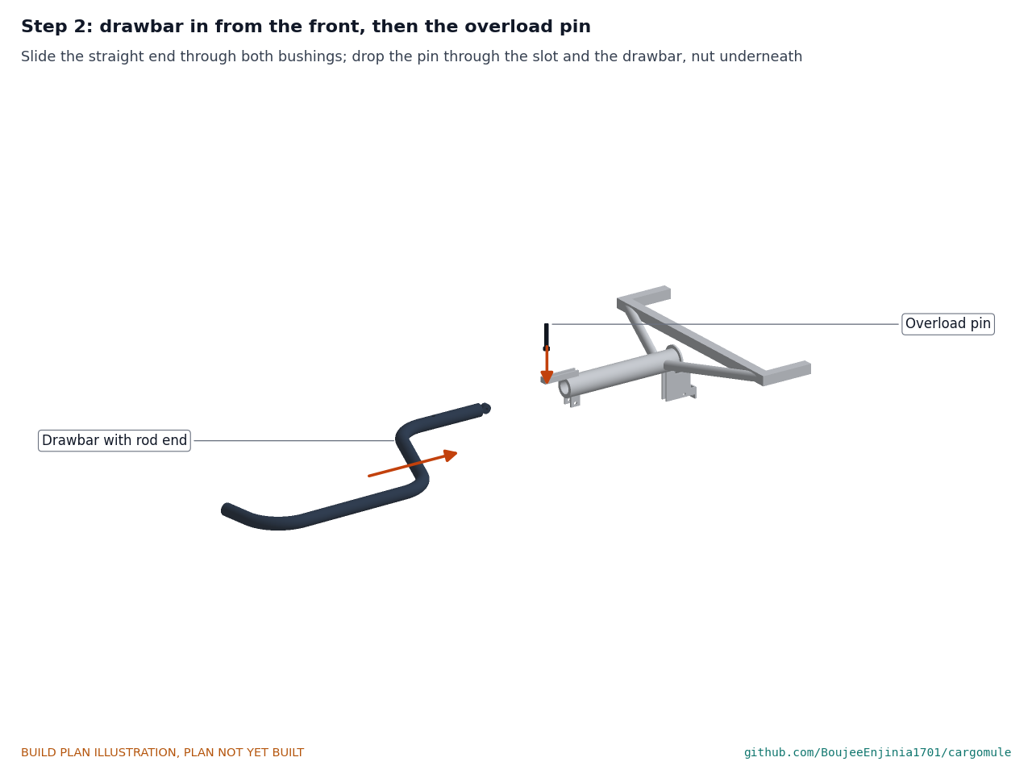
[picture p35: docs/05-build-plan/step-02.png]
Step 2


Screw the rod end into the drawbar's plug with threadlocker, eye upright. Slide the drawbar's straight end into the front of the housing through both bushings until its pin hole lines up under the fork's slot. Drop the M12 shoulder bolt through the slot and the drawbar and fit its nyloc nut underneath.

### Step 3: load cell cartridge in from the rear, then the end cap

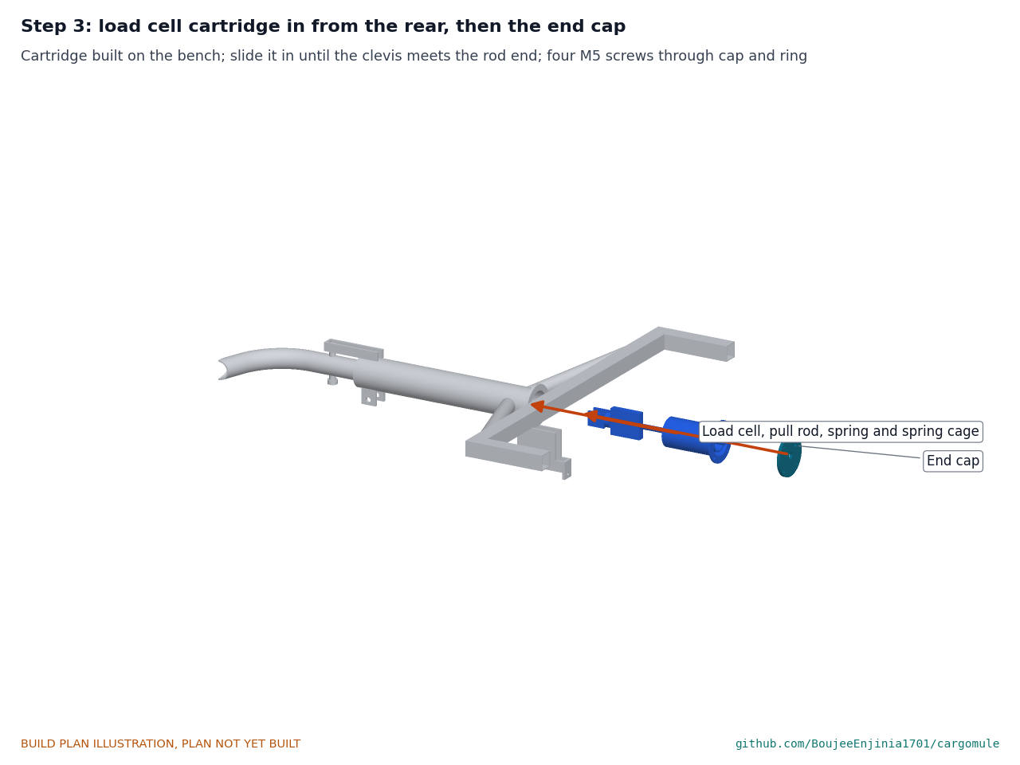
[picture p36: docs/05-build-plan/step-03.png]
Step 3


At the bench, screw the clevis onto the load cell's front thread and the pull rod into its rear thread, both with threadlocker; thread the cell's cable alongside. Pass the rod through the cage's bulkhead, fit the spring seat washer and nut, set the spring behind them and feed the cable through the bulkhead's cable hole. Slide the whole cartridge into the housing's rear until the clevis meets the rod end; fit the end cap over the rod's tail and the cable, and clamp cap and ring to the flange with four M5 screws. **Hold point:** the overload pin must rest 0.5 mm behind the slot's front end (check with a 0.5 mm feeler gauge); if not, take the end cap off and move the nut on the pull rod.

### Step 4: clevis pin through the side window

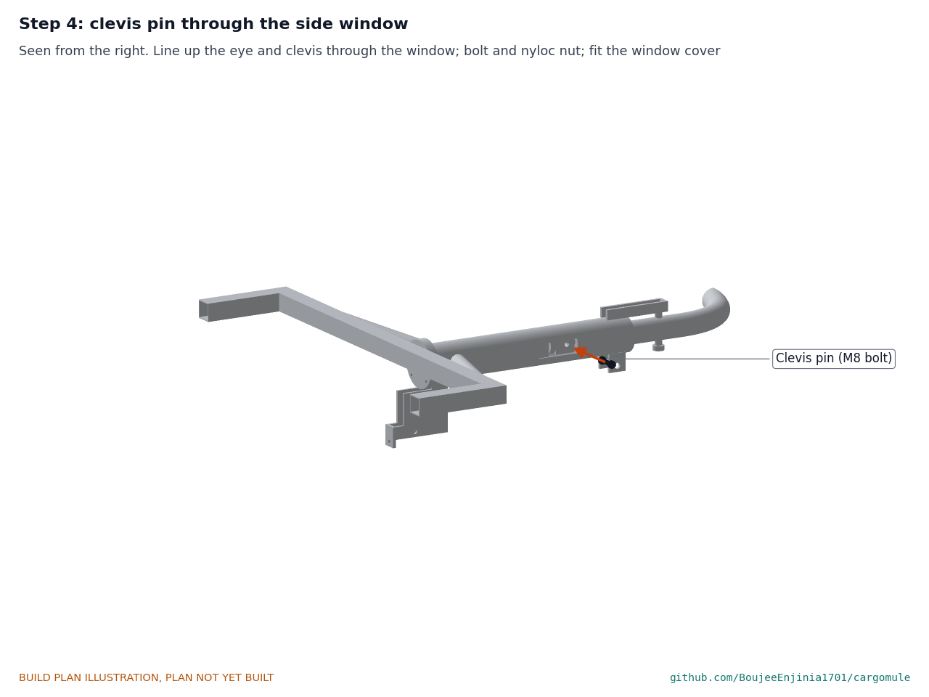
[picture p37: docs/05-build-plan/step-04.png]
Step 4


Seen from the right. Line up the rod end's eye between the clevis plates through the window and fit the M8 bolt and nyloc nut, snug. Fit the rubber window cover.

### Step 5: brake lever onto its cheeks

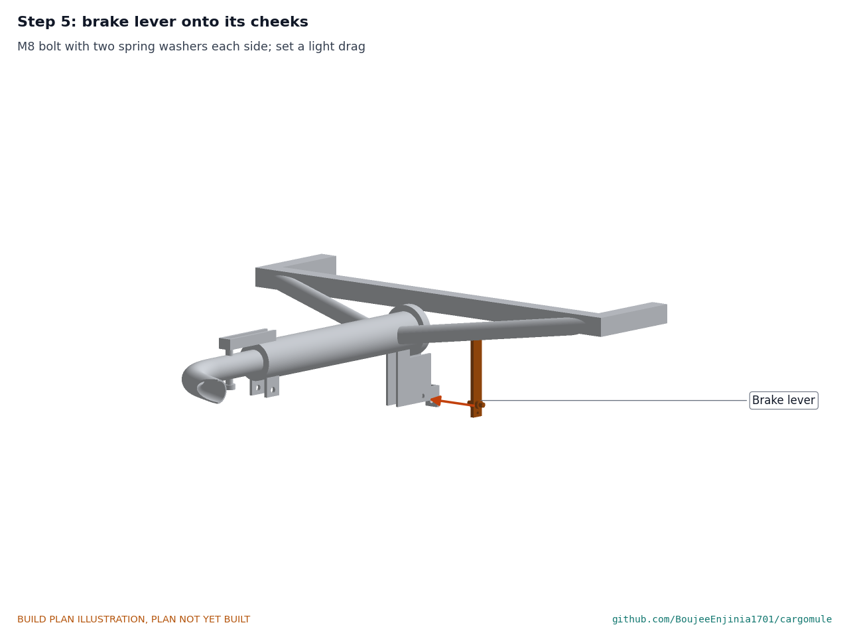
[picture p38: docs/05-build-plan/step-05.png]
Step 5


M8 bolt through the cheeks and lever, two spring washers each side of the lever, nyloc nut; tighten until the lever swings with a light, even drag. Check there is a 2 mm gap between the rod's tail and the lever.

### Step 6: parking stand into its clevis

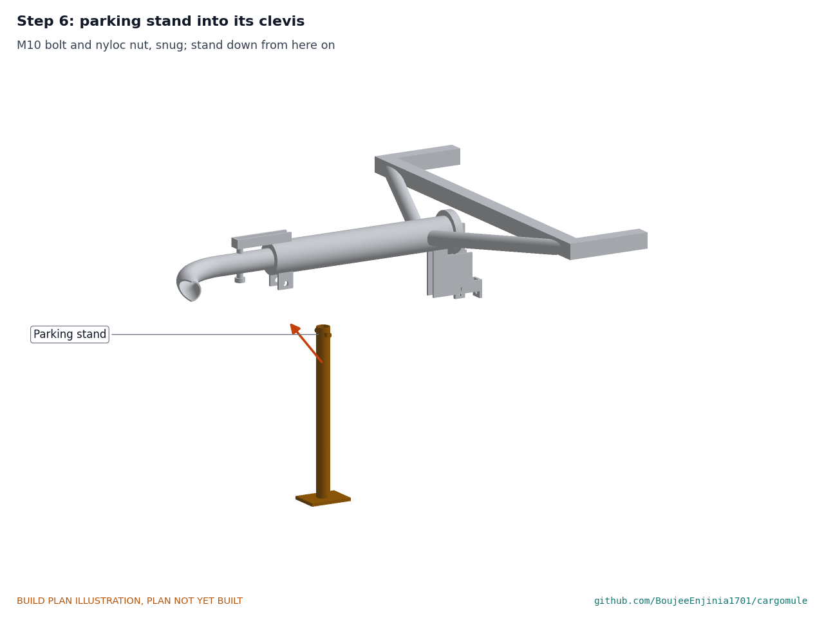
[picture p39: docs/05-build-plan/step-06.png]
Step 6


M10 bolt and nyloc nut, snug. Use the stand from here on whenever the trailer is off the trestles.

### Step 7: wheels into the dropouts

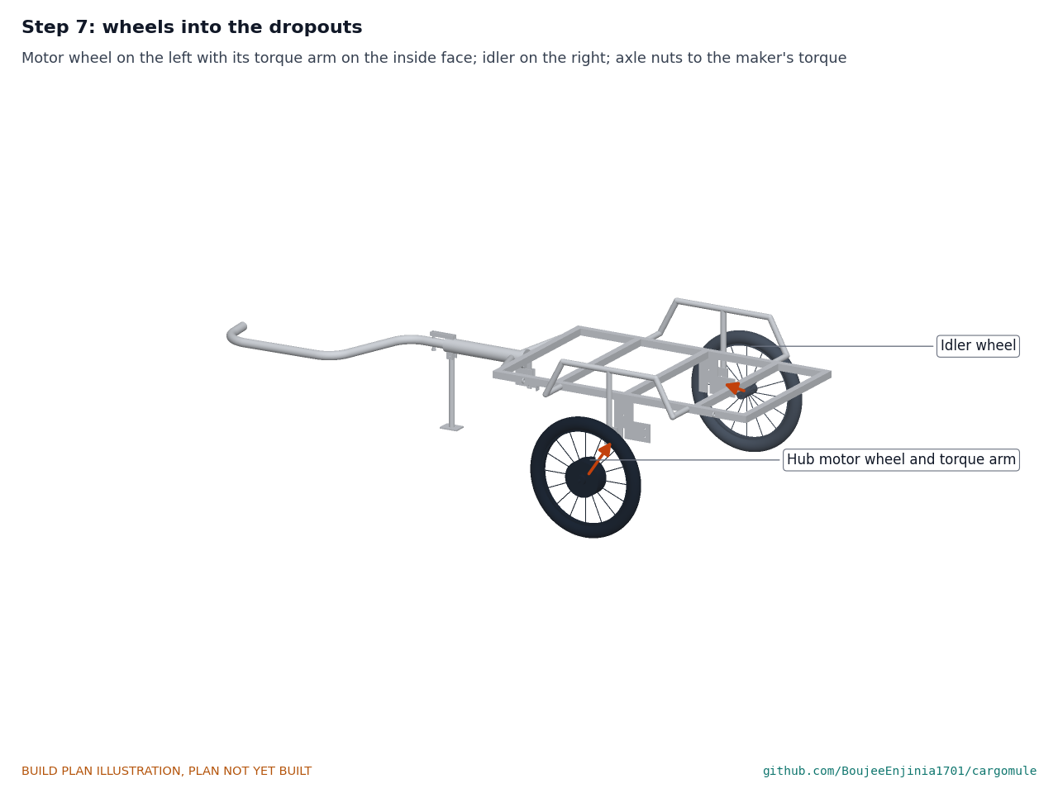
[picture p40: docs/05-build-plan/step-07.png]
Step 7


Rotors already on the hubs (section 3.11). Lift each wheel up into its slots from below: the motor wheel on the left with its cable on the outside, the idler on the right. On the motor wheel, fit the torque arm over the axle flats on the inner plate's inside face and bolt it to the plate. Tighten the axle nuts and quick-release to the makers' torque.

### Step 8: calipers onto the dropout tabs

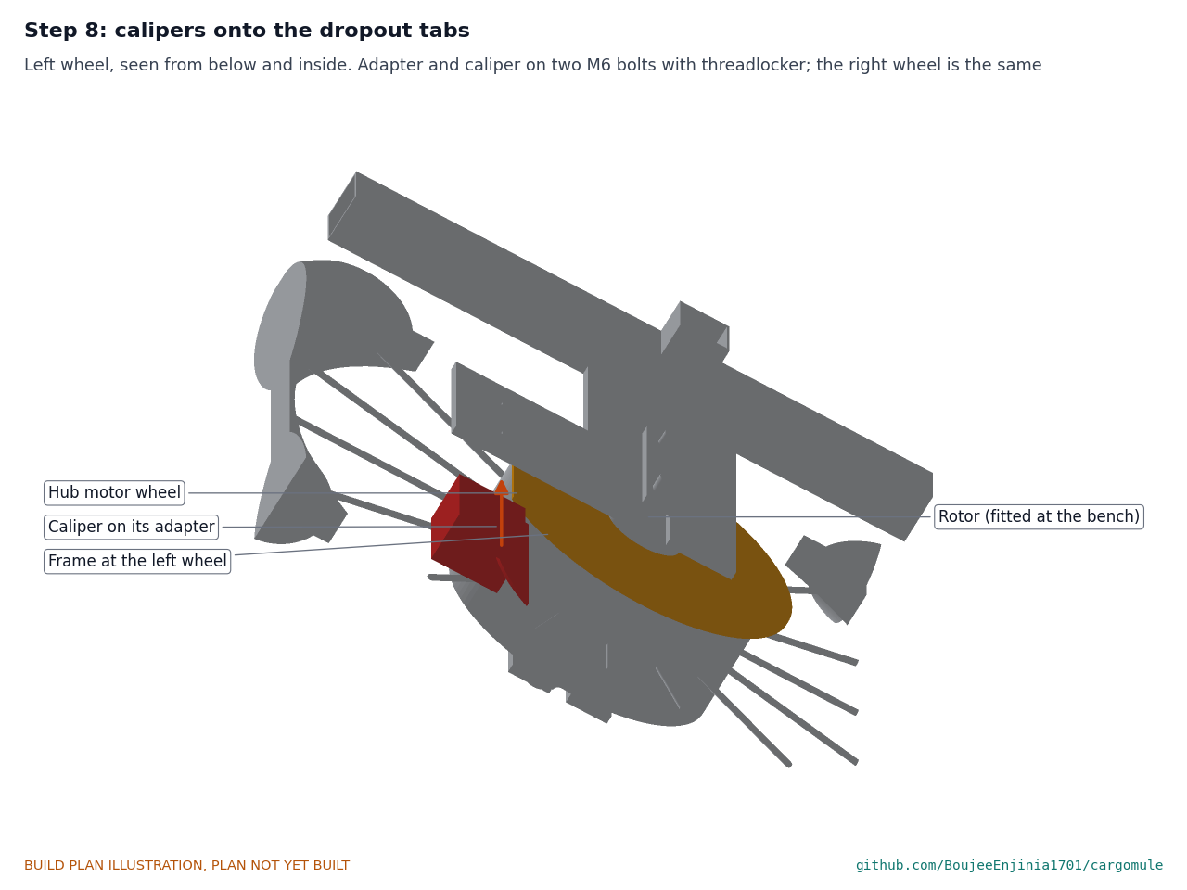
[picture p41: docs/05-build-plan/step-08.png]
Step 8


Seen from below. Bolt each adapter to its tab with two M6 bolts and threadlocker, then the caliper to the adapter, centred over the rotor. Spin each wheel: the rotor must not touch the pads.

### Step 9: brake cables and splitter

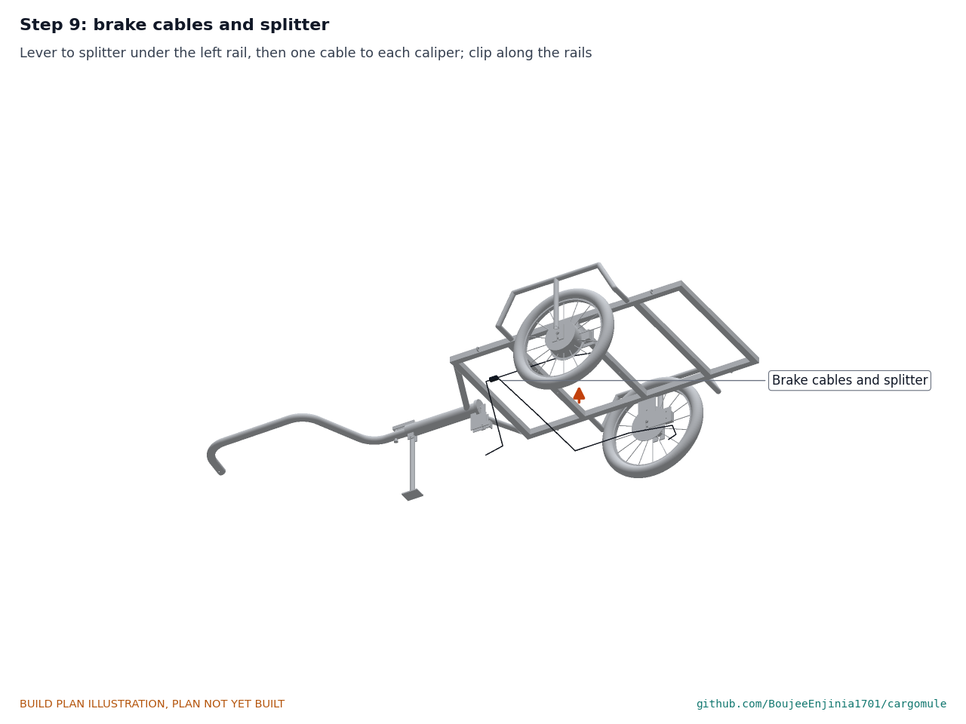
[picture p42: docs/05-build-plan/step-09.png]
Step 9


Clamp the input cable's inner wire in the lever's cable hole with its outer against the stop tab, and run it to the splitter clipped under the left rail. Run one cable from the splitter along each side rail to its caliper, clipped every 200 mm. Adjust so the calipers start to bite when the lever's top has moved about 3 mm.

### Step 10: enclosure under the crossmembers

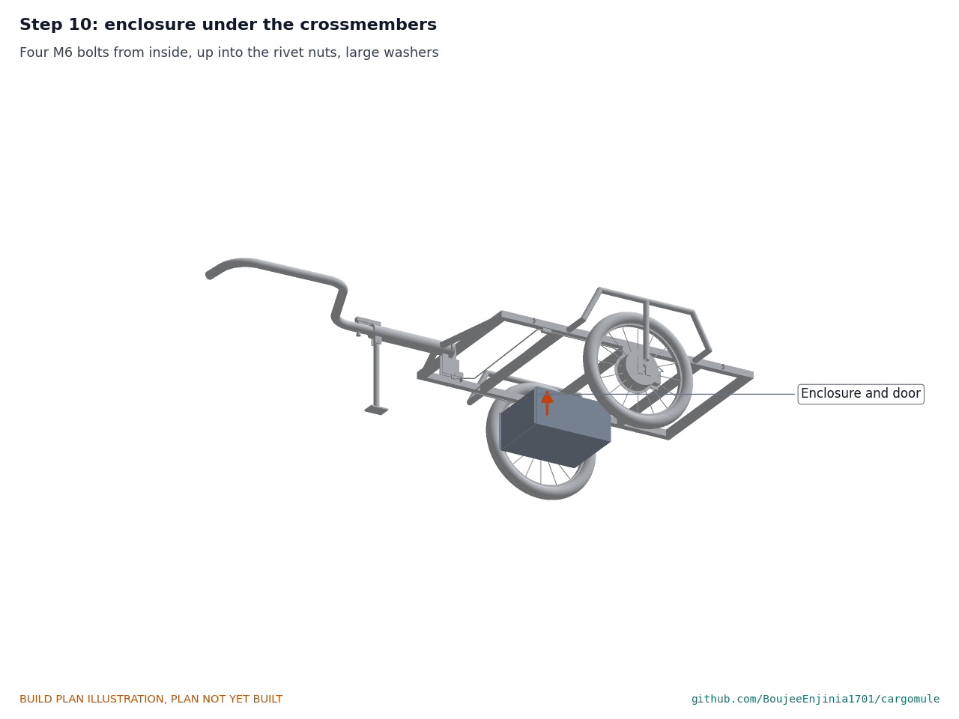
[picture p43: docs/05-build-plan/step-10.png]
Step 10


Seen from below. Hold the box up under the two crossmembers and fit the four M6 bolts from inside with large washers, through the open door.

### Step 11: controller, control board and harness

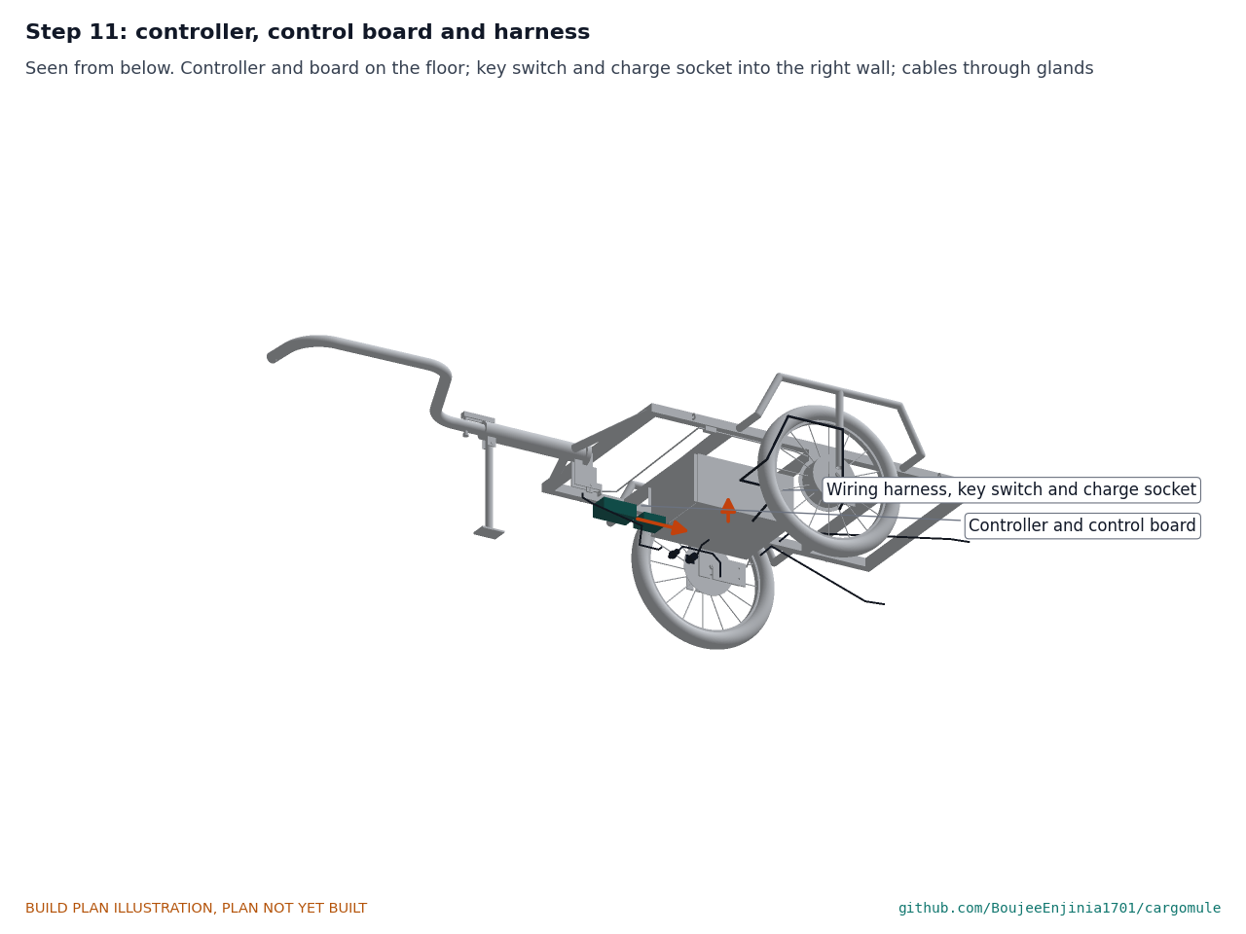
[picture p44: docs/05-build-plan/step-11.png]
Step 11


Screw the controller and the control board to the enclosure floor on the right, leaving the left free for the pack. Fit the key switch and the charge socket in their holes in the right wall from outside, with their seals, and tighten the switch's nut and the socket's two screws from inside. Run the key switch's lead over the controller to the control board, and the charge socket's lead toward the pack's side, where it plugs in at step 15; keep both leads inside the box and clipped away from the door. Run the motor cable from the motor's axle up the arch strut, along the arch frame and the left rail into the enclosure's left gland; the load cell cable from the end cap's gland under the deck to the right gland; the light cables from the rear gland to each rear light. Clip every cable to the frame, clear of the wheels and of the drawbar's 50 mm slide. **Hold point:** no pack yet; every connector checked against the harness maker's wiring diagram.

### Step 12: deck onto the frame

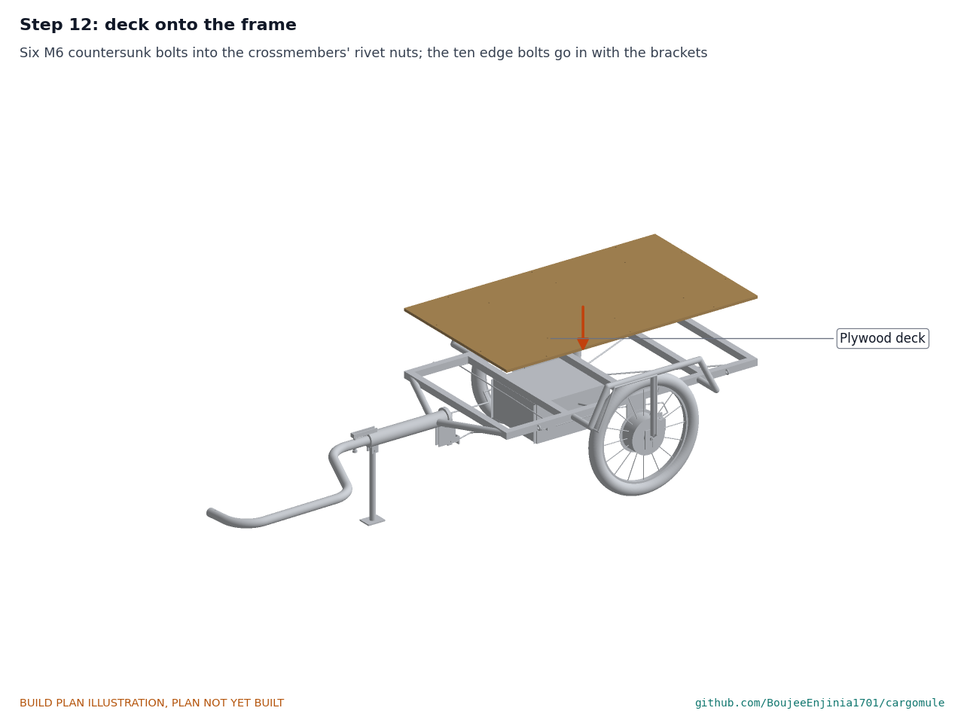
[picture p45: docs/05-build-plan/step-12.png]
Step 12


Lift the trailer off the trestles onto its wheels and stand. Lay the deck on the frame and fit six M6 countersunk bolts into the crossmembers' rivet nuts. The other ten holes, along the edges, take the bracket bolts in step 13.

### Step 13: boards, corner pieces and brackets

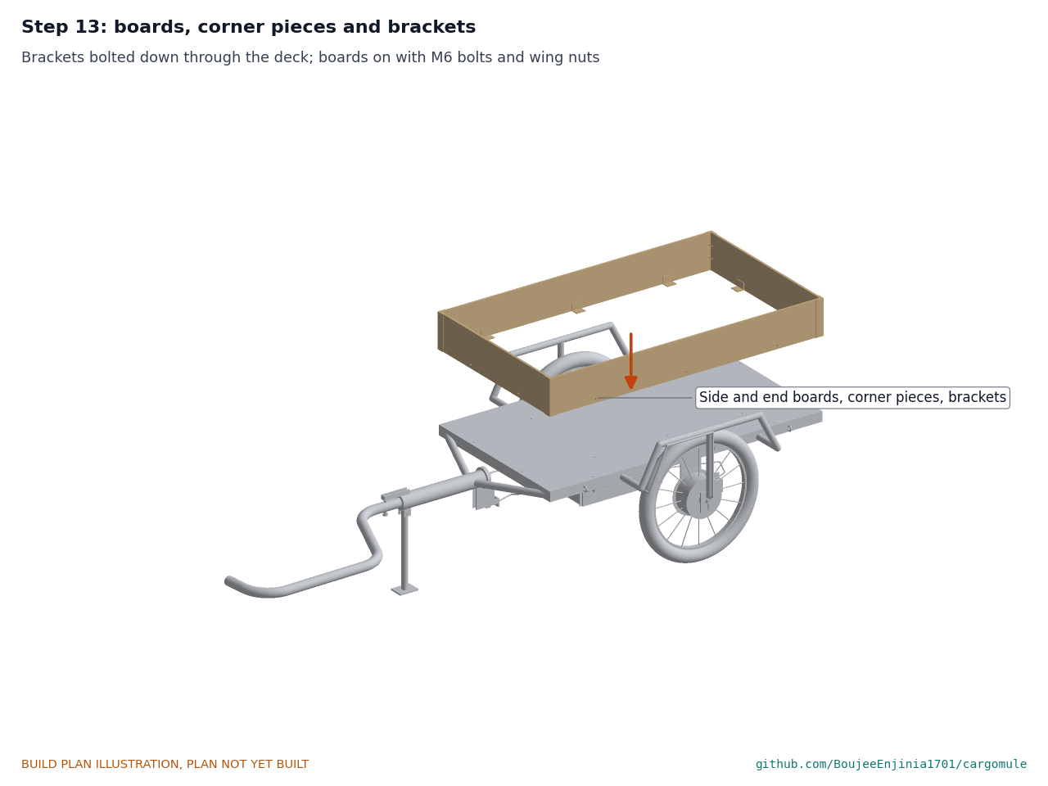
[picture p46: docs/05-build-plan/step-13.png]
Step 13


Bolt the ten brackets down through the deck into their rivet nuts. Stand the boards on the deck against the brackets and fit the M6 bolts and wing nuts; then the corner pieces with their wing nuts.

### Step 14: lights, reflectors and flag

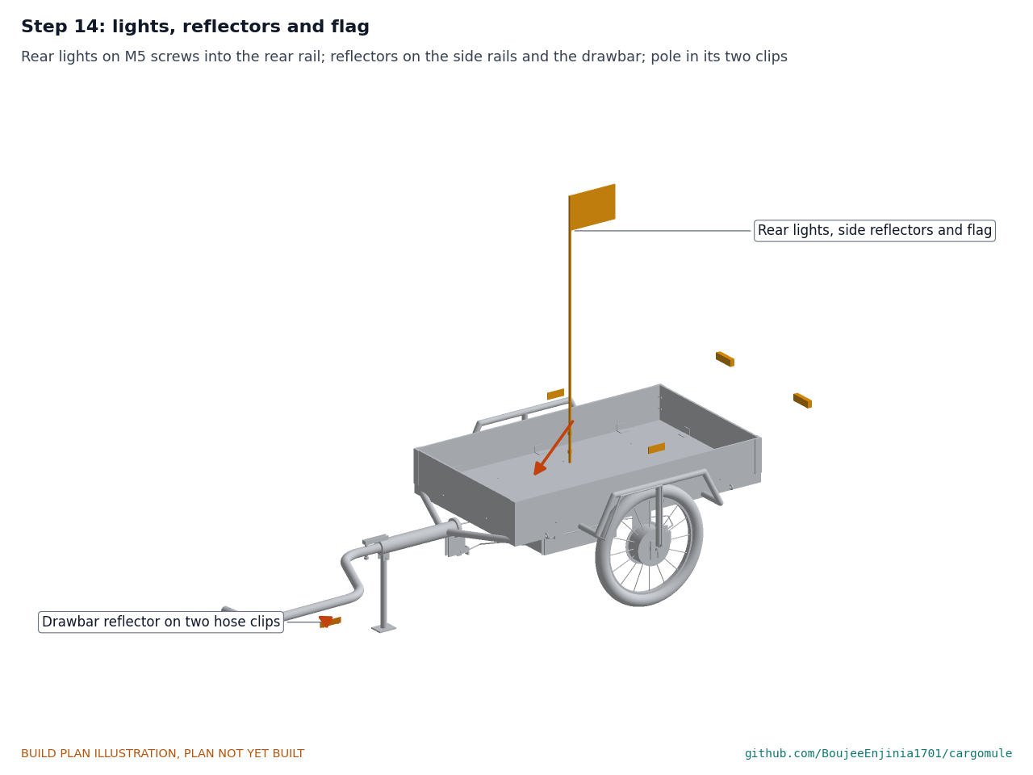
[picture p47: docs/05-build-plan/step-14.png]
Step 14


Rear lights on M5 screws into the rear rail's rivet nuts; plug in their cables. Side reflectors on the side rails' outer faces. Drawbar reflector on the outer face of the drawbar's long run beside the bicycle's rear wheel, centred about 280 mm behind the bicycle's axle, on its two hose clips. Flag pole into its two clips.

### Step 15: battery pack into the enclosure

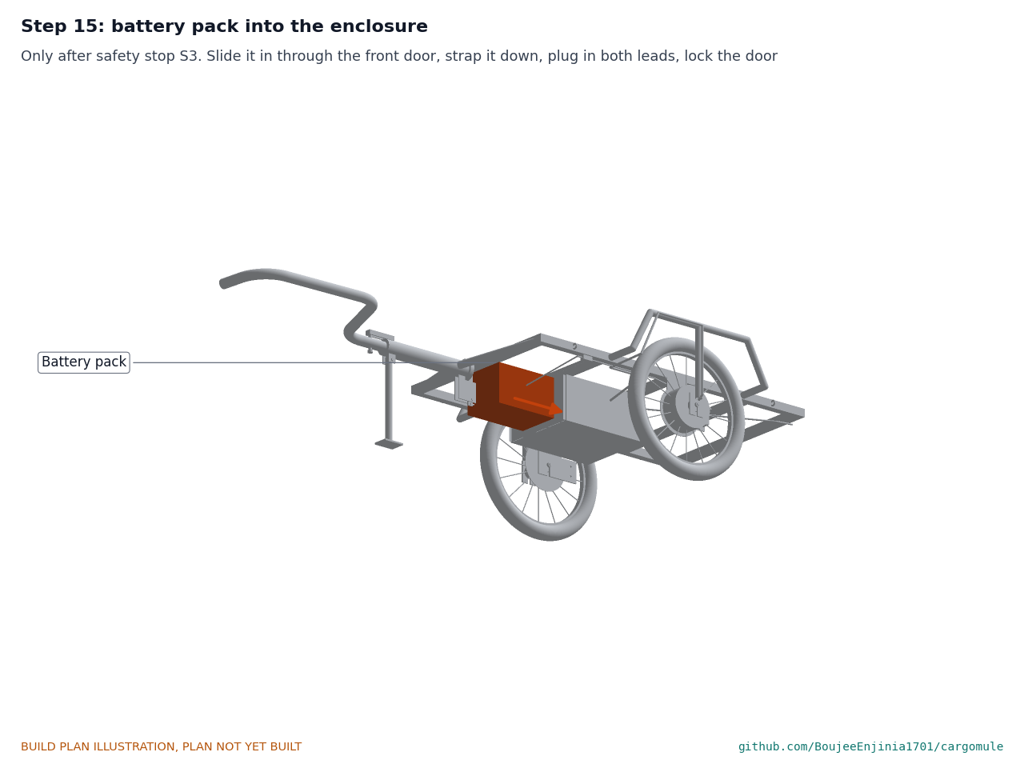
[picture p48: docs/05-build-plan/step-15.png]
Step 15


Seen from below with the deck left out. **Only after safety stop S3.** Slide the pack in through the door onto its mat, strap it down, plug in its power lead and the charge socket's lead, fit the fuse, close and lock the door. To take the pack out, unplug both leads first.

### Step 16: hitch onto the bicycle and into the drawbar

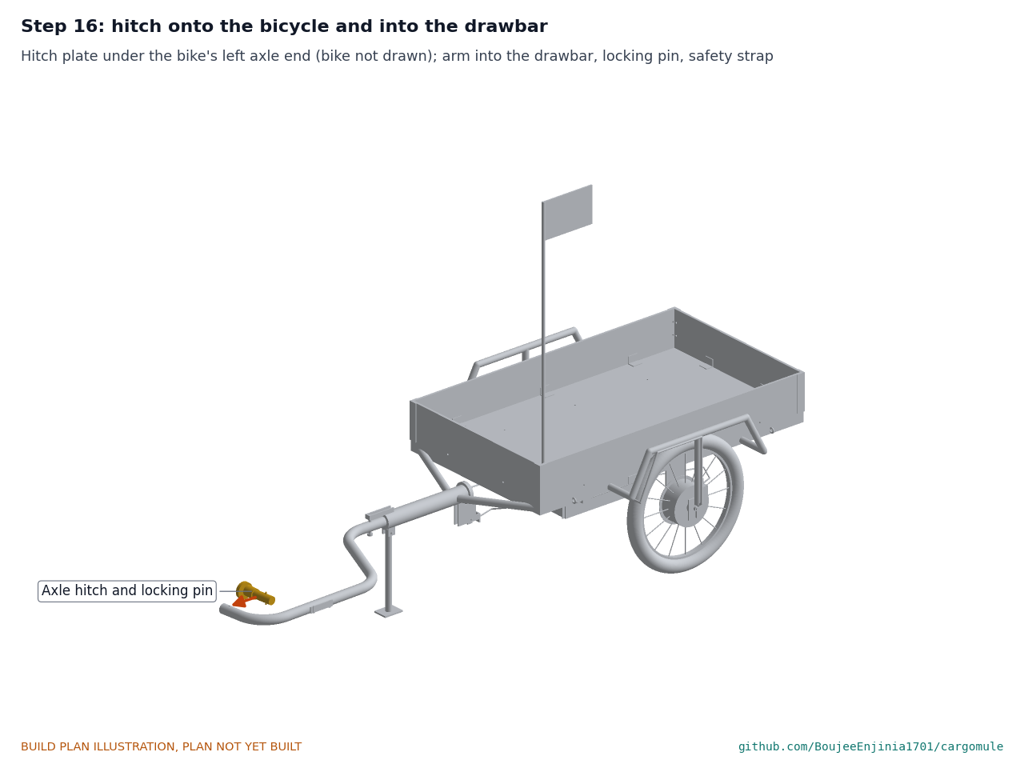
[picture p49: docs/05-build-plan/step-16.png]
Step 16


The bicycle is not drawn. Fit the hitch under the bicycle's left rear axle end as its maker describes. Lift the drawbar's front end, slide it over the hitch's arm, fit the locking pin and check the lock indicator, and fit the safety strap round the bicycle's chainstay. Fold the stand up. **Hold point:** safety stop S5.

## 5. First checks

These are the checks a TRL 4 test report would record; this plan only lists them. Requirement numbers are those of CGM-REQ-001.

*Table 2. First checks.*

| Check | Requirement | How | Pass when |
| --- | --- | --- | --- |
| Coupler slides | R6 | Trailer on its stand, bike unhitched; push the drawbar back by hand with a spring balance | It starts to move at about 30 N, slides 50 mm smoothly and springs back; no binding |
| Brakes apply on overrun | R6 | Push the drawbar back with the wheels lifted; turn each wheel by hand | Both wheels lock before 50 mm of slide; each rotor runs free at rest |
| Brake gain | R6 | Spring balance on the drawbar against a known brake torque at each wheel | About 7.8 N of braking force at the tyres per N of push above the preload, dry |
| Overload stop | R1, R13 | Pull the drawbar forward against a fixed hitch with a spring balance or load cell | The pin meets the slot's end with 0.5 mm of travel; the cell's reading stops rising there |
| Load cell reads both ways | R4, R6 | Amplifier output while pulling and pushing the drawbar by hand at 10 to 40 N | Reading follows the force in both directions within 1 N, and returns to zero |
| Assist cut on push | R6, R13 | Bench supply in place of the pack, motor wheel lifted; command assist, then push the drawbar | Motor current falls to zero within 100 ms of 20 N of push |
| Assist only in tension | R5 | Wheel lifted; no pull, then pull above 3 N | No motor current without pull; current rises in proportion to pull |
| Fault cut | R13 | Unplug the load cell while assisting | Motor current zero within 100 ms; the brakes still work |
| Articulation | R7, R9 | Hitched to a bicycle, swing the trailer through a turn both ways | The drawbar clears the rear tyre to about 55 degrees toward the drawbar side |
| Hitch load | R10 | Bathroom scale under the hitch with 150 kg of sandbags centred in the loading zone | 3 to 10 kg (7.5 kg estimated) |
| Mass | R8 | Weigh the empty trailer with the pack | 47 kg or less, the prototype cap (46.3 kg estimated) |
| Size | R9 | Tape measure | 1,000 mm or less wide; 2.6 m or less from the bicycle's axle |
| Lights, reflectors and flag | R14 | Look; measure the flag's top | Lights on from the pack; side and drawbar reflectors fitted; flag top 1.5 m or more above the ground |

## 6. Safety stops

Stop at each point. Carry on only when everything listed is true.

- **S1. Before any welding.** The area is clear of anything that burns; a fire extinguisher is in reach; the welder wears a helmet, gloves and leathers; nobody else watches the arc unprotected. No welding on the frame once the pack, controller or harness are fitted.
- **S2. Before the tube bender is used.** The bender is bolted down; hands are clear of the die; the tube is supported at its free end.
- **S3. Before the pack comes into the workshop.** The pack's voltage is 36 to 43 V and its case is undamaged and dry; a charging spot is ready on a non-combustible surface with a fire extinguisher for electrical fires within reach; the 20 A fuse is out; every connector has been checked for polarity with a meter, not by wire colour.
- **S4. Before the motor first turns.** The motor wheel is off the ground; hands, cables and clothing are clear of the spokes; the assist cut on push and the fault cut (section 5) pass with a current-limited bench supply in place of the pack.
- **S5. Before the trailer is hitched or loaded.** Every bolt is tight with its nut or threadlocker; the overload pin and clevis pin are in; both brakes lock on a push of the drawbar with the power off; the hitch's lock indicator shows locked and the safety strap is on; the stand is up.
- **S6. Before the first loaded roll.** On private, level ground only, at walking pace, with the load strapped down inside the loading zone. Never on a public road: its legal status is not settled.
- **S7. Charging.** Only through the charge socket in the enclosure's right wall, with the key switch off, with the charger on the bill of materials, on the charging spot, attended, never below 0 °C and never with a damaged or wet pack.

## 7. Tools, skills and workspace

**Tools.** Metal-cutting bandsaw or chop saw and hacksaw; tube bender with a 38 mm die and 115 mm centre-line radius (or a fabricator's bender); MIG or stick welder for 1.5 to 6 mm steel; angle grinder with cutting, grinding and flap discs; bench drill and hand drill; drills 3 to 12.5 mm; M5 and M10 taps; step drill; files, deburring tool and a 56 mm hone or flap wheel for the housing's bore; rivet nut tool for M5 and M6; sheet metal folder or bending brake for 0.8 mm sheet 350 mm long, aviation snips and a pop rivet tool; circular saw or jigsaw for plywood; welding table or flat floor area 1.5 x 1 m; two trestles about 500 mm high; spirit level, steel rule, tape, square, calipers and a 0.5 mm feeler gauge; spanners and sockets 8 to 19 mm; torque wrench; spring balance to 200 N; multimeter; bench power supply with a current limit (0 to 45 V, 0 to 5 A); bathroom scale; crimper and wire strippers.

**Skills.** Steel fabrication and welding of thin-wall tube, tube bending, sheet folding, bicycle brake and wheel fitting, and low-voltage wiring with plug-in connectors. The welding should be done or checked by a competent welder. All circuits on the trailer are extra-low voltage (43.8 V at most on charge); the charger is a certified unit and no mains wiring is part of this build.

**Workspace.** A workshop area about 3 x 2 m with a welding corner kept apart from the electrical bench; ventilation for welding fumes and paint; the charging spot of S3.

**Personal protective equipment.** Welding helmet, gloves and leathers; safety glasses for cutting, grinding and drilling; hearing protection for sawing and grinding; cut-resistant gloves for sheet metal; safety boots when lifting the frame; no gloves near a turning drill.

## 8. Where the numbers come from

- Model and constructability checks: `cad/src/model.py` (`python cad/src/model.py --check`, 86 checks); STEP and STL exports in `cad/step/` and `cad/stl/`.
- Pictures: `cad/src/build_plan_media.py`, using `.kit/build_views.py`; written to `docs/05-build-plan/` and `cad/drawings/CGM-DWG-101` to `CGM-DWG-111`.
- General arrangement: `cad/drawings/CGM-DWG-001.pdf`, Rev P5.
- Calculations: `docs/04-calcs/01-sizing.md` (CGM-CAL-001 v0.6) and `docs/04-calcs/sizing.py`: masses [A1] to [A3], hitch load and loading zone [A6], [A7], brake gain and push [F3], [F4], drawbar strength [G3], [G4], articulation [H5].
- Bill of materials: `bom/bom.csv`.
- Decisions: `docs/decisions/0003-design-for-construction.md` (CGM-DDR-003), with CGM-DDR-001 and CGM-DDR-002.
- Requirements: `docs/03-requirements.md` (CGM-REQ-001 v0.8).

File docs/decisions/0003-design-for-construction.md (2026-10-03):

---
doc_id: CGM-DDR-003
title: CargoMule design for construction
project: CargoMule
doc_type: Design decision record
version: "0.4"
status: Draft
date: '2026-10-02'
author: Amish Chadha
license: CERN-OHL-S-2.0
revisions:
- version: "0.1"
  date: '2026-10-01'
  author: Amish Chadha
  change: Changes that make the concept physically buildable, with the reason for each; made under Amish's 2026-09-30 instruction to make the design physically buildable; open for his review
- version: "0.2"
  date: '2026-10-01'
  author: Amish Chadha
  change: Budget treated as a value-engineering target; cost wording only, no number changed
- version: "0.3"
  date: '2026-10-02'
  author: Amish Chadha
  change: "Table 3 (A1 to A4) accepted by Amish as recommended on 2026-10-02; record stays Draft"
- version: "0.4"
  date: '2026-10-02'
  author: Amish Chadha
  change: "Table 1 changes (P1 to P15) accepted by Amish on 2026-10-02; record stays Draft"
---

# 0003: Design for construction

- **Date:** 2026-10-01
- **Status:** accepted. Amish, 2026-10-02: "APPROVED: Design-for-construction changes in 10 repos (CityTwin, CoolShade, PalletPilot, Heliolite, PotholeLog, EarthPress, ReadyKit, CellCheck, CargoMule and ThermaCart)". This covers the changes P1 to P15 in Table 1, made under Amish's 2026-09-30 instruction to make the design physically buildable, and is recorded in the design decisions register (CGM-DEC-001). The items in Table 3 change a requirement status or the product's appearance; Amish accepted all four as recommended earlier the same day: "i approve your recommendations for all 555 open decisions." They are recorded in the design decisions register (CGM-DEC-001). The record stays Draft.

## Context

On 2026-09-30 Amish asked for every repo's build plan to show how each component is made and how it fits the next, with pictures, and wrote: "If you are realising that the design cannot be built as per concept - fix the design assumptions to match and be physically feasible as you draw the illustrations." The TRL 3 model of CargoMule (CGM-DDR-002) was a massing model: it showed what the trailer does and carried the right main dimensions, but many of its parts could not be made, fixed or assembled as drawn. Checking it with build123d found parts that overlapped (the calipers ran into the hub motor, the harness ran through the coupler, load cell, stand and enclosure), parts with no fixing (deck, boards, enclosure, lights, flag, stand) and a load path that could not work (a load cell on pinned ends carrying the drawbar's bending). Working out the assembly order found three more problems that an overlap check cannot see (P3, P4 and P8 below).

The changes keep what CargoMule does: the same deck, wheels, track, hitch point and drawbar route, the same proportional assist sensed at the drawbar, the same mechanical overrun brake on both wheels with the same 30 N preload, 50 mm stroke and 7.7 to 1 lever, the same 384 Wh pack, motor and controller. Nothing here changes the pitch or the safety case. Every change is in `cad/src/model.py`, which now runs 73 constructability checks (`python cad/src/model.py --check`): parts that must touch do touch, parts that must not touch keep the stated clearance, and the coupler's moving parts are checked again at full stroke. All 73 pass.

## Decision

*Table 1. Changes made to the model, the BOM and the calculations.*

| # | Problem in the concept | Change made | Why this way |
| --- | --- | --- | --- |
| P1 | The load cell sat in the drawbar line on pinned clevises, between the drawbar and a separate sliding coupler. A pinned link cannot carry the drawbar's bending or the 7.5 kg tongue load, so the drawbar would fold at the cell; the coupler's force path was not defined. | The drawbar's straight rear end is the coupler's sliding member: it runs in two acetal bushings in a 60.3 x 2.0 mm steel housing welded into the frame nose, so the bushings carry bending and the tongue load. Inside the housing, in series: a rod end on the drawbar's end plug, a clevis pin, the S-type cell, an M10 pull rod and a nut and washer that bear on the bulkhead of a spring cage. A 30 N preload spring sits behind the nut. Pull goes drawbar, cell, rod, bulkhead, cage, housing. Push above 30 N slides the drawbar, cell and rod back against the spring, and the rod's tail pushes the brake lever. | The cell sees only axial force, in both directions, as the concept intended (it reads true push up to the brake's onset, so the 20 N compression cut still works). The concept's preload, stroke and lever ratio are unchanged. |
| P2 | No overload stop could be built in the concept's layout, and nothing stopped the offset drawbar rolling in a round sleeve. | A slotted fork welded on top of the housing's front end, its front end closed by a plate. An M12 shoulder bolt through the drawbar rides in the slot: it stops the drawbar turning, and it sits 0.5 mm behind the closed end, so a pull beyond the cell's travel bears on the housing instead of the cell. | One part does both jobs. A 12 mm pin keeps the bending stress about 180 MPa at the 1.9 kN ultimate pull. |
| P3 | The cell string could not be put into the housing: a collar on the drawbar was wider than the bushing bore and the bulkhead was welded in. | The spring, pull rod, cell and spring cage form a cartridge that goes in from the rear and is held by a ring clamped under a bolted end cap. The drawbar goes in from the front carrying its rod end. The two are joined by an M8 clevis pin put in through a 70 x 24 mm window in the housing's right side, closed by a rubber cover. | Every part can be fitted and taken out with hand tools, in one order. The window is behind the bushings, where the housing carries no drawbar bending. |
| P4 | The brake lever and damper were boxes with no pivot or cable path; the hydraulic damper had no mounting. | A 20 x 6 mm lever pivoted on an M8 bolt between two 4 mm cheeks under the housing's rear, 106 mm above and 13.8 mm below the pivot (7.7 to 1). The rod's tail pushes its top; its bottom pulls one cable through a stop tab to a splitter under the left rail, then one cable to each caliper. Damping comes from spring washers on the pivot (friction), which the concept allowed as an alternative to a small hydraulic damper. | A cable splitter replaces the equalizer bar and needs no mounting of its own. See A3 for the damping choice. |
| P5 | The drawbar's corners were sharp with balls at the knees; its straight section started 800 mm from the hitch, leaving too little straight tube for the coupler. | One 38 x 2.5 mm S355 tube with three 115 mm radius bends made in a tube bender; the straight rear part starts at 700 mm (centre line corner) so 198 mm of straight tube runs in the bushings. The hitch end's knee positions are unchanged, so the 55.5 degree articulation (CGM-CAL-001 H5) is unchanged. | A bent tube can be made by any fabricator with a bender. The drawbar is 0.1 kg heavier. |
| P6 | The nose bars met in a solid ball; they started inside the front rail. | The nose bars run from the front rail's face to the sides of the coupler housing, fishmouthed onto it, 320 mm behind its front end. | The housing is the nose: one welded joint replaces a part that could not be made. |
| P7 | The hitch arm (34 mm) was larger than the drawbar's 33 mm bore. | Hitch arm 32 mm, 60 mm into the bore, with a 6 mm locking pin through both. | A sliding fit with 0.5 mm clearance. |
| P8 | The enclosure was an open box touching one crossmember with no fixing. Its lid was on top, against the frame, so it could not open, and the pack could not come out. | The box is 350 mm long (was 320) and centred under the crossmembers at 1,600 and 1,920 mm, held by four M6 bolts from inside into rivet nuts in the crossmembers. A front door, hinged along its bottom edge with a keyed lock, opens toward the drawbar; the pack slides out forward under the deck. | The box hangs from two crossmembers with a 15 mm bolt edge distance. The forward path is the only one clear of the wheels and rotors. The box's mass center moves 260 mm rearward. |
| P9 | The calipers overlapped the hub motor's shell (caliper body from 65 mm radius against a 78 mm shell) and had nothing to mount to. | Each inner dropout plate extends rearward as a tab; the caliper's post-mount adapter bolts to it with two M6 bolts and the caliper body sits 80 to 120 mm from the axle, 2 mm clear of the motor shell. The rotor sits 15 mm inside the hub's locknut face. | Standard bicycle parts and dimensions. |
| P10 | The dropout plates had no axle slots; the motor's torque (about 35 N m on the climb) had nothing to react it but the axle flats. | 10.2 mm slots, 40 mm deep from the bottom edge, in all four plates. A bought torque arm on the left inner plate's inside face, bolted to the plate with one M6 bolt. | The wheels drop in from below. Hub motor makers call for a torque arm in steel dropouts. |
| P11 | The deck and boards had no fixing. | Sixteen M6 countersunk bolts through the deck into rivet nuts in the rail tops. The boards are held by four aluminium angle corner pieces and ten aluminium angle brackets with M6 wing nuts, so they still come off by hand. | Rivet nuts put threads in closed box section without welding nuts inside. |
| P12 | The flag pole stood on the deck with no fixing. Rear lights floated 2 mm behind the rear rail. | The pole sits in two clips on the left board's inside face. The lights bolt to the rear rail with M5 screws into rivet nuts. | |
| P13 | The parking stand's top had nothing to attach to. | The stand leg pivots on an M10 bolt in a clevis under the housing's front end and folds back under the housing. | |
| P14 | The harness was drawn through the coupler, load cell, stand and enclosure. | Rerouted. The motor cable runs from the axle's outer end up the arch strut and along the arch frame, clipped outside it, to the left rail and the enclosure. The cell cable leaves through a gland in the end cap. The light cables run under the deck. | The motor cable outside the left arch makes the trailer 972 mm wide over the cable (960 mm over the frame); R9 (1,000 mm) is still met. |
| P15 | Rails and tubes were solid. | Rails, crossmembers, nose bars and arch frames are modelled as hollow sections with capped ends where open ends would face forward or rearward. | Needed for the fixings and for honest masses. |

*Table 2. Knock-on changes.*

| Item | Change | Reason |
| --- | --- | --- |
| Mass | Empty trailer 46.2 kg (was 43.2 kg) [A3]: frame 13.0 kg from the model (dropout tabs, eyes), coupler 2.9 kg in all (was 1.6 kg), board fittings 0.5 kg, enclosure 3.0 kg, torque arm and splitter 0.2 kg. R8 (45 kg) is **not met**; see A1. | The concept's masses were estimates for parts that had not been designed. |
| Balance | Hitch load 7.5 kg with the payload centred (was 7.8 kg) [A6]; loading window 32 mm ahead to 57 mm behind the deck centre [A7]. R10 still met. | Enclosure moved rearward; coupler heavier. |
| Performance | Felt pull on the 8 % climb 38.7 N (was 36.6 N, R3 target 40 N) [C3]; range 24.5 km (was 24.9 km) [E3]; push 93 N dry and 111 N wet (was 92 N and 110 N) [F3], [F4]. Statuses unchanged: R3 and R6 at risk, R2 met. | The trailer is 3 kg heavier. |
| Structure | Drawbar factor 4.3 at the coupler's front bushing [G3] (was 3.0, quoted at the nose); ultimate case 1.6 unchanged [G4]. | The drawbar is now held by the bushing, 320 mm ahead of the old nose point. |
| Cost | BOM lines 2, 5, 6, 7, 9, 10, 15, 16 and 18 respecified; total $997 (was $979) against the unchanged $1,000 value-engineering target `budget_usd`, $3 under it [I1]. | Fittings, rivet nuts, coupler parts. |
| Drawing | CGM-DWG-001 Rev P4; making sketches CGM-DWG-101 to 111 added. | Follows the model. |
| Documents | CGM-CAL-001 v0.3, CGM-PRC-001 v0.5, CGM-REQ-001 v0.5. R8 changes from met to not met; no other requirement changes status. | Follows the model. |

*Table 3. Items that change a requirement status or the appearance: proposed, then accepted by Amish as recommended on 2026-10-02.*

| # | Question | Options | Recommendation |
| --- | --- | --- | --- |
| A1 | The constructable trailer weighs 46.2 kg, 1.2 kg over R8's 45 kg. | (a) relax R8 to 47 kg for the first prototype and weigh it at TRL 4; (b) take the later weight option of CGM-DDR-002 now: straps or mesh in place of the plywood side boards (about 43.9 kg); (c) look for mass elsewhere (4 mm dropout plates, a shorter housing with a stiffer spring), about 0.5 kg. | (a). The boards are part of what the trailer offers; the margin is small and the estimate is on catalogue masses. Accepted by Amish, 2026-10-02 ("i approve your recommendations for all 555 open decisions."): R8 becomes 47 kg as a hard cap for the first prototype only, not a new target; weigh at TRL 4; straps or mesh side boards if the weighed trailer is over 47 kg. |
| A2 | The key switch and charge port. The renders of 2026-09-26 put them on the enclosure's front face, which is now the door. | (a) on the enclosure's right wall near the front, reached under the deck edge; (b) on the door, with a flexible lead across the hinge. | (a): no cable flexes at the hinge. Accepted by Amish, 2026-10-02 ("i approve your recommendations for all 555 open decisions."): (a). |
| A3 | Friction damping on the lever pivot in place of a small hydraulic damper (the concept allowed either). | (a) friction washers for the prototype; (b) a small hydraulic damper between the cheeks and the lever. | (a), and check at TRL 4 that the coupler does not chatter on rough roads; (b) fits later without other changes. Accepted by Amish, 2026-10-02 ("i approve your recommendations for all 555 open decisions."): (a), with the rough-road chatter check made a pass condition at TRL 4; fit (b) if the brake chatters or grabs. |
| A4 | The photoreal renders and the appearance model (`cad/src/product_model.py`) show the concept's coupler, load cell guard, top-opening enclosure with an inspection window and the old harness. | (a) update the appearance model and renders on Amish's Mac to this design; (b) leave them until TRL 4. | (a), before the repo is made public. Accepted by Amish, 2026-10-02 ("i approve your recommendations for all 555 open decisions."): (a), before the repo is made public. |

## Consequences

- `design_state: constructable` in `project.yaml`. The build plan CGM-BLD-001 shows every component and step in pictures generated from the model (`cad/src/build_plan_media.py`).
- Requirement status (CGM-CAL-001 v0.3): one not met (R8), three at risk (R3, R6, R7), eight met on paper or by design, two not verifiable at TRL 3.
- The renders `media/render-*.png`, `media/card.png` and `media/social-preview.png` and the appearance model still show the concept; with A4 accepted they are to be updated on Amish's Mac before the repo is made public.
- With A1 accepted, R8 is a 47 kg cap for the first prototype (CGM-REQ-001 v0.7) and is met on paper at 46.2 kg; the trailer is weighed at TRL 4. With A2 and A3 accepted, the key switch and charge port go on the enclosure's right wall, and the coupler is damped by friction washers with a chatter check at TRL 4.
- The parts to confirm when bought (load cell size, hub motor axle and cable exit, caliper adapter, spring) are listed in the design decisions register, CGM-DEC-001.

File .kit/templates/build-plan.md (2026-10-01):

---
doc_id: PRJ-BLD-001
title: Project prototype build plan
project: Project name
doc_type: Build plan
version: "0.1"
status: Draft
date: YYYY-MM-DD
author: Amish Chadha
license: CERN-OHL-S-2.0
revisions:
  - version: "0.1"
    date: YYYY-MM-DD
    author: Amish Chadha
    change: First build plan; design made constructable
---

# Project prototype build plan

**Plan, not yet built.** How to build the first proof-of-concept prototype, component by component. Building and testing to it is TRL 4 work. Decisions still to be made are kept in the design decisions register (`docs/06-design-decisions.md`), not here.

## 1. What you are building

Every component, pulled apart and numbered in build order

One short paragraph: what the prototype is, how many components, which are made and which are bought, and the main ways they are made.

## 2. What changed to make it buildable

| Component | The concept had | The buildable design has | Why |
| --- | --- | --- | --- |

## 3. Making the components

### 3.1 Component name

Making sketch

**What it is and what it is made from.**

**How to make it.**

1. Mark out ...
2. Cut ...

**How it fits the parts next to it.**

Close-up of the joint

**Check before moving on.**

## 4. Putting it together

### Step 1: ...

Step 1

## 5. First checks

| Check | Requirement | How | Pass when |
| --- | --- | --- | --- |

## 6. Safety stops

## 7. Tools, skills and workspace

## 8. Where the numbers come from

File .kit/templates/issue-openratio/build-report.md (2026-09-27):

---
name: Build report
about: Tell us what happened when you built, printed or tested part of this design
title: "Build report: "
labels: build-report
---

This is a research and educational prototype, not a medical device. It is a TRL 3 concept and is not released for fabrication. If you build any part of it, you do so at your own risk. Reports help everyone.

**What you built** (part, sub-assembly or test)

**Materials, tools and settings**

**What worked**

**What did not work, with photos or measurements if you have them**

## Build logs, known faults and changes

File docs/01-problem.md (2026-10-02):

---
doc_id: CGM-PRB-001
title: CargoMule problem statement
project: CargoMule
doc_type: Problem statement
version: "0.6"
status: Draft
date: '2026-10-02'
author: Amish Chadha
license: CERN-OHL-S-2.0
revisions:
- version: "0.1"
  date: '2026-09-24'
  author: Amish Chadha
  change: Initial scaffold
- version: "0.2"
  date: '2026-09-25'
  author: Amish Chadha
  change: Populate to TRL 2 (users, context, constraints, out of scope, prior work with sources)
- version: "0.3"
  date: '2026-09-25'
  author: Amish Chadha
  change: TRL 3. Pitch wording "most bicycles" and $1,000 budget per CGM-DDR-001; open questions linked to the decision record
- version: "0.4"
  date: '2026-09-26'
  author: Amish Chadha
  change: Stronger sources
- version: "0.5"
  date: '2026-10-01'
  author: Amish Chadha
  change: Budget treated as a value-engineering target; cost wording only, no number changed
- version: "0.6"
  date: '2026-10-02'
  author: Amish Chadha
  change: "Open questions O1 and O2 answered by Amish's 2026-10-02 decisions (first candidate user type; private ground only until a legal check)"
---

# CargoMule problem statement

Small businesses and households need to move 100 to 150 kg loads a few kilometers at a time, but a mainstream cargo e-bike lists at about $2,400, the few electric-assist trailers on the market cost as much or more, and an ordinary bicycle cannot pull that weight up a hill. CargoMule aims to turn the bicycle a person already owns into a 150 kg load carrier for well under the price of a cargo e-bike.

## The problem

Short urban and suburban trips with heavy loads (a market stall's stock, tools and materials for a trade job, a week of groceries for a large household, a delivery round) are usually made by car or van. A bicycle with a cargo trailer can do many of these trips, but the rider becomes the limit:

1. **Hills.** On level ground most people can pull about 137 kg (300 lb) on a trailer at modest speed, but a 2 % grade already triples the effort and a 4 % grade needs very low gearing ([Bikes At Work](https://www.bikesatwork.com/blog/how-much-weight-can-a-bicycle-carry)). A first-order estimate for CargoMule's design load (about 188 kg of loaded trailer) on an 8 % grade is about 165 N of extra pull, or about 370 W at 8 km/h on top of the rider's own climb. That is beyond most riders.
2. **Cost of the alternatives.** A mainstream electric longtail such as the RadWagon 5 lists at $2,399 ([Rad Power Bikes](https://www.radpowerbikes.com/products/radwagon-electric-cargo-bike)). Commercial electric-assist trailers exist but are priced for businesses (see Prior work).
3. **Braking.** A heavy trailer without its own brakes pushes the bicycle when it slows. Voluntary trailer standards set low limits for unbraked trailers: 60 kg in EN 15918 and 45.4 kg (100 lb) in ASTM F1975 ([Wikipedia summary of both standards](https://en.wikipedia.org/wiki/Bicycle_trailer); [EN 15918 catalog entry](https://standards.iteh.ai/catalog/standards/cen/e11b5f02-592a-45fb-9a47-3d8c2c11275d/en-15918-2011a2-2017)). A 150 kg trailer therefore needs its own brakes.

CargoMule is an electric-assist cargo trailer that hitches to most bicycles with no wiring to the bike. A load cell in the drawbar measures how hard the bicycle is pulling and the trailer's hub motor pushes in proportion, so the rider feels a fraction of the trailer's load on the flat and on hills.

## Users and context

| User | Need | Context |
| --- | --- | --- |
| Market trader or street vendor | Move 80 to 150 kg of stock and a stall between storage and market | Early starts, mixed roads, curbs, parking at the stall |
| Tradesperson (gardener, painter, bike mechanic) | Carry tools and materials to jobs within about 10 km | Daily use, loads vary through the day, hills |
| Household without a car | Weekly shopping, moving furniture, bulk goods | Occasional use, stored in a shed or hallway |
| Community group, food bank or repair café | Pick up and deliver donations; share the trailer among members | Several riders and bikes; must hitch quickly to any bike |
| Local workshop or maker | Build and repair the trailer from common parts | Hand tools, a welder in some cases, e-bike parts suppliers |

### Operating environment

- **Roads:** paved streets, bike lanes and compacted gravel paths, with curbs, drop kerbs and grades up to about 8 % on short climbs (10 % occasionally).
- **Loads:** 100 to 150 kg of payload on the deck; towing bicycle and rider about 90 to 110 kg.
- **Speed:** 10 to 20 km/h cruising; assisted speed limited to 25 km/h in line with pedelec rules.
- **Climate:** −10 to 40 °C, rain, road spray and winter salt in some regions.
- **Charging:** household mains at home or at the business; charged overnight.

## Constraints

- Garage-buildable prototype, with a $1,000 USD value-engineering target for parts (`project.yaml`, a hypothetical control target, not a limit; raised from $900 by CGM-DDR-001, D1).
- Hitches to most bicycles with no change to the bike and no wiring to it: bikes with a quick-release or thru-axle rear wheel first, with adapters for others (see CGM-REQ-001, R7).
- Assist within e-bike limits: 250 W rated power and assist to 25 km/h at most, matching the EU pedal-assist exclusion in Regulation (EU) No 168/2013 ([EUR-Lex](https://eur-lex.europa.eu/legal-content/EN/TXT/PDF/?uri=CELEX%3A32013R0168)) and within the US federal low-speed electric bicycle definition of under 750 W and 20 mph ([15 U.S.C. 2085](https://www.law.cornell.edu/uscode/text/15/2085)). Whether a motorized trailer falls under these rules is an open question.
- The trailer must brake itself so it never pushes the bicycle hard when slowing.
- Generic, replaceable parts (e-bike hub motor, controller, disc brakes, 20 in wheels) so a local bike shop can repair it.

## Out of scope

- A complete cargo bicycle or tricycle (see FlatTrike).
- Carrying people or children.
- Handcart or walk-behind mode (kept out of scope by CGM-DDR-001, D10).
- Designing the battery cells or BMS (a bought-in 36 V LiFePO4 pack, CGM-DDR-001 D2; a SwapCell receiver is a later fleet variant).
- Road registration or type approval.

## Prior work

- **Carla Cargo (Germany).** A heavy-duty trailer with an optional 250 W hub motor, 150 kg payload in its original version and an overrun brake with dual discs ([New Atlas](https://newatlas.com/carla-cargo-bike-trailer/43044/)). Its current eCARLA carries up to 200 kg, uses a Bafang hub motor and a 720 Wh LiFePO4 pack, assists to 25 km/h and starts at €6,490 ([Carla Cargo](https://www.carlacargo.de/products/ecarla)). The early version sensed pedaling through a crank sensor fitted to the towing bike, which ties the trailer to one bike.
- **Biomega Ein.** A single-wheel electric trailer with a 250 W hub motor that detects the bike's motion from its own wheel speed and pushes in proportion; about $1,428 planned retail ([New Atlas](https://newatlas.com/bicycles/biomega-ein-electric-bicycle-trailer/)). It is a light-load design.
- **Roland PAXXTER e.** A box trailer with two 125 W, 36 V hub motors, a 180 Wh pack and a pedal sensor, sold at about €3,300 ([Notebookcheck](https://www.notebookcheck.net/Roland-PAXXTER-e-Bicycle-Trailer-launches-as-new-cargo-bike-kit.763538.0.html)).
- **Brake-controlling couplings.** A Brüggli patent application describes a trailer coupling that senses relative movement between two housing parts to control the trailer's brakes ([WO2022223692A1](https://patents.google.com/patent/WO2022223692A1/en)), and a German utility model covers a bicycle trailer coupling for an overrun brake ([DE202010010674U1](https://patents.google.com/patent/DE202010010674U1/en)). These confirm that sensing at the coupling works for braking. CargoMule uses a load cell at the coupling for propulsion as well, and a freedom-to-operate check is needed before release.
- **Unpowered heavy trailers.** Commercial cargo trailers carry 14 to 140 kg ([Wikipedia](https://en.wikipedia.org/wiki/Bicycle_trailer)), and heavy-haul builders show 137 kg is a practical unassisted limit on level ground ([Bikes At Work](https://www.bikesatwork.com/blog/how-much-weight-can-a-bicycle-carry)).

The gap CargoMule addresses is an open, garage-buildable design that senses pull force at the drawbar, so it needs no sensor or wiring on the towing bike, carries 150 kg with its own brakes, and costs a fraction of a commercial electric trailer.

## Open questions

- Is a motorized bicycle trailer legal on public roads and bike lanes in the first target country, and under which category? Carla Cargo's sale in Germany suggests a path in the EU; US state rules need checking. Decided by Amish, 2026-10-02 (CGM-DDR-001, O2): private ground only until a written legal check exists for the first partner's country.
- Which users first: a market trader group, a trades cooperative, or a community food bank? Decided by Amish, 2026-10-02 (CGM-DDR-001, O1): a group moving 50 to 150 kg loads on short, repeated urban trips on paved, hilly routes; the first candidate type to approach is a community food bank's local delivery or pantry runs, with market traders second. No partner is agreed.
- Is 150 kg the right payload, or do most target loads fall under 100 kg, which would allow a lighter trailer?
- How many target bikes have a quick-release or thru-axle rear wheel, and what share need a nutted-axle or hub-gear adapter?

## User research and co-design

- [ ] Identify two or three target users (trader, tradesperson, community group) and record their typical loads, routes and storage space
- [ ] Ride typical routes with a loaded unpowered trailer and log grades and speeds
- [ ] Validate payload, range and cost assumptions with users
- [ ] Revise requirements (REQ) from findings before freezing the design

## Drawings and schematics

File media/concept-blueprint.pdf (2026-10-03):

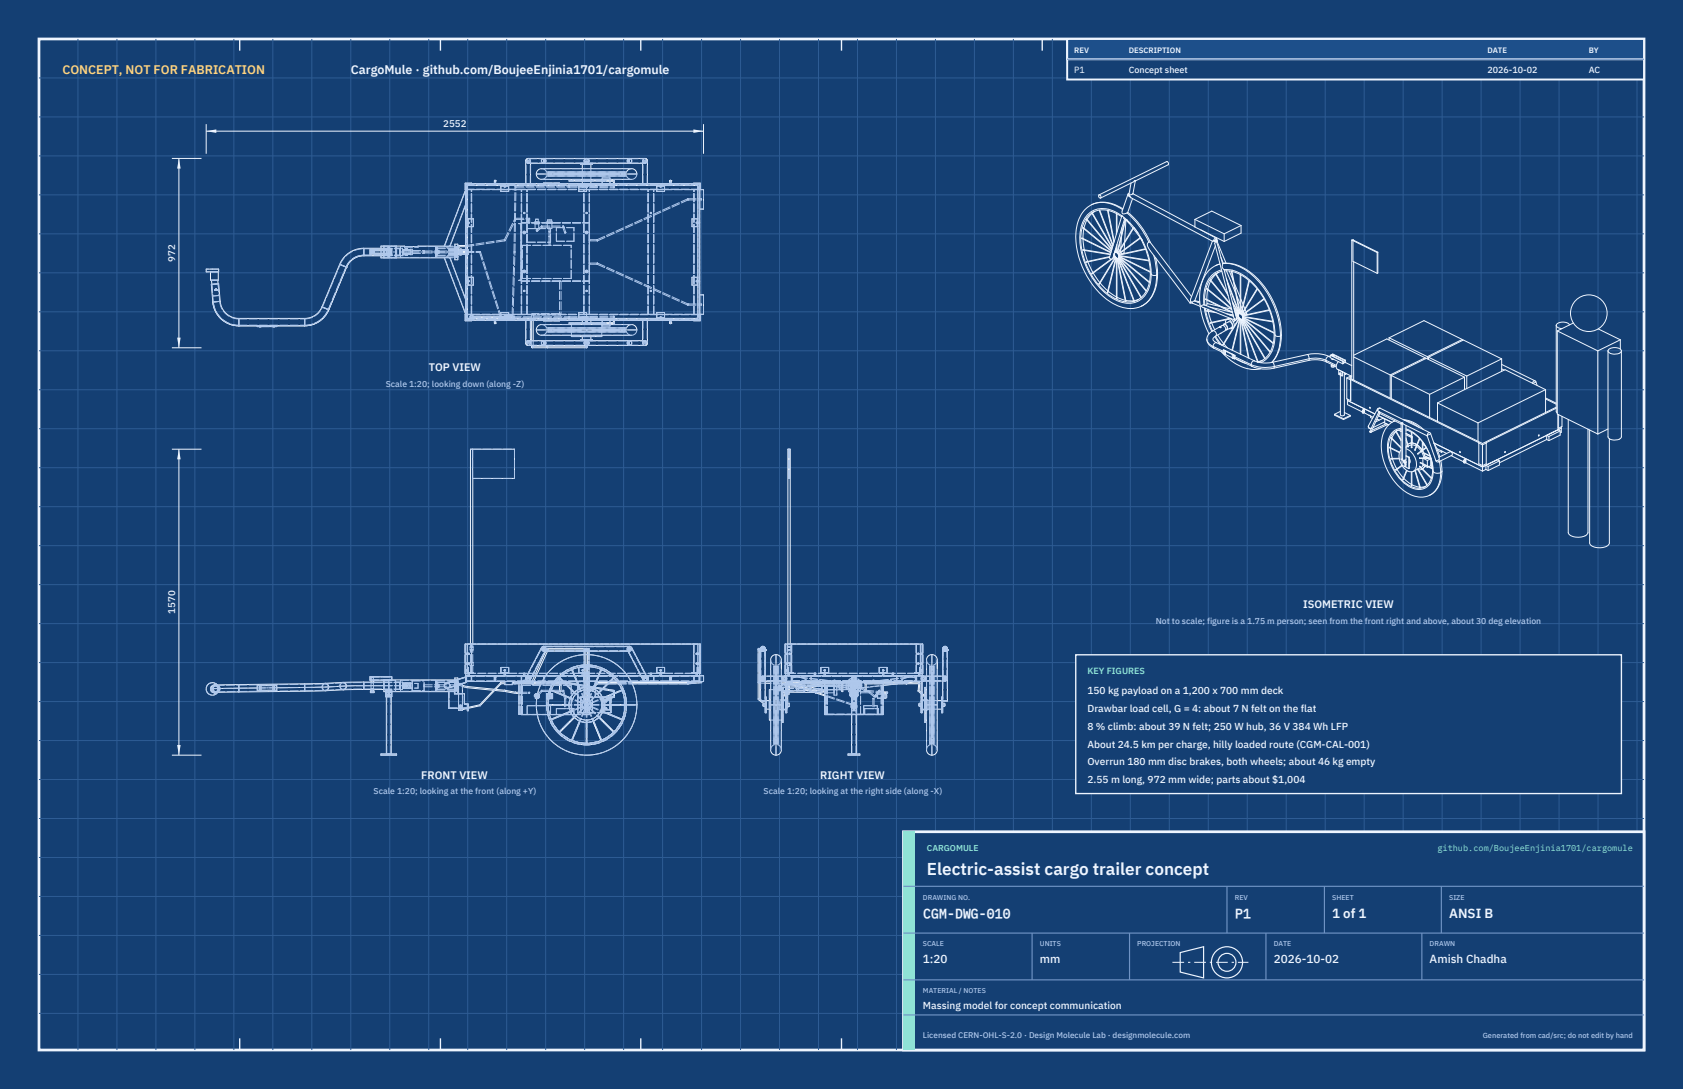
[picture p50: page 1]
CONCEPT, NOT FOR FABRICATION; CargoMule · github.com/BoujeeEnjinia1701/cargomule; FRONT VIEW; TOP VIEW; RIGHT VIEW; ISOMETRIC VIEW; REV; DESCRIPTION; DATE; Concept sheet; CARGOMULE; github.com/BoujeeEnjinia1701/cargomule; DRAWING NO. CGM-DWG-010; REV P1; SHEET 1 of 1; SIZE ANSI B; SCALE 1:20; UNITS mm; PROJECTION; DRAWN Amish Chadha; Licensed CERN-OHL-S-2.0 · Design Molecule Lab · designmolecule.com; Generated from cad/src; do not edit by hand

Scale 1:20; looking down (along -Z)

Not to scale; figure is a 1.75 m person; seen from the front right and above, about 30 deg elevation

KEY FIGURES
150 kg payload on a 1,200 x 700 mm deck
Drawbar load cell, G = 4: about 7 N felt on the flat
8 % climb: about 39 N felt; 250 W hub, 36 V 384 Wh LFP
About 24.5 km per charge, hilly loaded route (CGM-CAL-001)
Overrun 180 mm disc brakes, both wheels; about 46 kg empty
2.55 m long, 972 mm wide; parts about $1,004

Scale 1:20; looking at the front (along +Y)

Scale 1:20; looking at the right side (along -X)

Electric-assist cargo trailer concept

MATERIAL / NOTES
Massing model for concept communication

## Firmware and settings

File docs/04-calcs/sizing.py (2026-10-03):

"""CargoMule sizing calculations, CGM-CAL-001 v0.6 (TRL 3; constructable design per CGM-DDR-003,
with the decisions of 2026-10-02 carried in).

Run from the repo root:  python docs/04-calcs/sizing.py
Prints every number that CGM-CAL-001 (docs/04-calcs/01-sizing.md) quotes, each on a line
tagged like [A1]. Geometry comes from cad/src/model.py (PARAMS, derived and, for the masses of
made steel parts, the volumes of the modelled components), so the calc
note, the STEP files and drawing CGM-DWG-001 use the same dimensions. The BOM total is read
from bom/bom.csv and the budget from project.yaml. First-principles estimates for a paper
proof of concept; every assumption is set in the ASSUMPTIONS block below.
"""
import csv
import sys
from math import atan2, cos, degrees, exp, hypot, pi, radians, sin, sqrt
from pathlib import Path

import numpy as np
import yaml

ROOT = Path(__file__).resolve().parents[2]
sys.path.insert(0, str(ROOT / "cad" / "src"))
from model import PARAMS as P, derived, drawbar_points, build_components  # noqa: E402

D = derived(P)
g = 9.81

# ------------------------------------------------------------------ ASSUMPTIONS
A = {
    # masses and loads
    "payload": 150.0, "payload_cg_above_deck": 150.0, "bike_rider": 100.0,
    "steel_rho": 7850.0, "ply_rho": 550.0,
    # resistance
    "crr": 0.010, "cda_extra": 0.10, "rho_air": 1.2,
    # control
    "G": 4.0, "G_range": (2.0, 6.0), "deadband": 3.0,
    # motor: 250 W geared front-style hub, 20 in wheel, DC-equivalent model (to confirm from the datasheet)
    "v_pack": 38.4, "v_pack_low": 36.0, "no_load_rpm": 230.0, "R_motor": 0.35, "eta_gear": 0.90,
    "P_iron": 8.0, "eta_ctrl": 0.95, "I_batt_max": 15.0, "I_phase_max": 30.0,
    "Rth": 1.2, "Cth": 700.0, "T_amb": 30.0, "T_limit": 100.0,
    # pack and charging
    "pack_Wh": 384.0, "usable": 0.90, "eta_charger": 0.90, "eta_cell": 0.96, "pack_Ah": 10.0, "charge_A": 4.0,
    # loop dynamics
    "zeta_s": 0.05, "fs": 80.0, "t_ctrl": 0.020, "k_range": (20e3, 50e3, 100e3, 200e3, 500e3),
    # braking
    "decel": 3.0, "push_max": 100.0, "preload": 30.0, "mu_dry": 0.40, "mu_wet": 0.30,
    "caliper_ratio": 4.0, "cable_travel": 3.5, "lever": 7.7, "c_steel": 460.0, "h_rotor": 60.0,
    "rotor_m_160": 0.12, "rotor_area_160": 0.025, "reaction": 1.0,
    # structure
    "fy_s355": 355.0, "fy_s235": 235.0, "fy_axle": 650.0, "ply_allow": 10.0,
    "n_bump": 2.0, "n_tongue": 3.0, "ult_long_g": 1.0, "hitch_lever": 12.0,
}

# 180 mm rotors (CGM-DDR-002): mass and cooled area scaled from a 160 mm rotor by the braking annulus (hub bore 60 mm)
ROTOR_SCALE = ((P["rotor_d"] / 2) ** 2 - 30 ** 2) / (80 ** 2 - 30 ** 2)
A["rotor_m"] = A["rotor_m_160"] * ROTOR_SCALE
A["rotor_area"] = A["rotor_area_160"] * ROTOR_SCALE

# bought-in part masses, kg (typical catalog values, to confirm by weighing)
BOUGHT = {
    "4 Universal axle hitch": 0.60, "5 Load cell, rod end, clevis and amplifier": 0.45,
    "6 Coupler internals (bushings, spring, pull rod, nut, bolts)": 0.40,
    "7 Torque arm and bolt": 0.10, "9 Brake cable splitter and third cable": 0.12,
    "7 Hub motor wheel (geared hub 2.6 kg, rim, spokes, tyre 1.7 kg)": 4.30,
    "8 Idler wheel with disc hub": 1.90, "9 Disc brakes, two (caliper, 180 mm rotor, cable)": round(0.80 + 2 * (A["rotor_m"] - A["rotor_m_160"]), 2),
    "11 Battery pack, 12S LiFePO4 384 Wh with BMS": 4.20, "12 Motor controller": 0.40,
    "13 Control board": 0.15, "14 Harness, fuse, key switch and charge socket": 0.55,
    "15 Lights, reflectors (with the drawbar reflector) and flag": 0.55, "18 Hardware, paint and consumables": 0.80,
}

out = []


def say(tag, text):
    line = f"[{tag}] {text}"
    out.append(line)
    print(line)


def tube_area(od, t):
    return pi / 4 * (od ** 2 - (od - 2 * t) ** 2)


def tube_Z(od, t):
    return pi * (od ** 4 - (od - 2 * t) ** 4) / (32 * od)


def box_Z(b, t):
    return (b ** 4 - (b - 2 * t) ** 4) / 12 / (b / 2)


def dist(a, b):
    return sqrt(sum((a[i] - b[i]) ** 2 for i in range(3)))


print("CargoMule sizing, CGM-CAL-001. Units SI unless stated; lengths from cad/src/model.py in mm.\n")

# ================================================================== A. Mass and balance
rho = A["steel_rho"] / 1e9          # kg/mm3
hw, x0, x1, ax = D["hw"], P["deck_x0"], D["deck_x1"], P["axle_x"]
R, rt = P["rail"], P["rail_t"]
COMP = build_components(P)
vol = lambda *ks: sum(COMP[k].shape.volume for k in ks)  # noqa: E731
m_box = vol("rails") * rho
m_nose = vol("nose_bars") * rho
m_arch = vol("arches") * rho
m_plates = vol("dropouts") * rho
zr = (D["fz0"] + D["fz1"]) / 2
m_frame = m_box + m_nose + m_arch + m_plates + 0.25      # 0.25 kg: weld metal, rivet nuts, end caps of open tubes
pts = drawbar_points(P)
m_drawbar = vol("drawbar") * rho                          # bent tube, end collar and anti-rotation pin
m_coupler = vol("housing", "cage", "end_cap", "lever") * rho
m_stand = vol("stand") * rho
m_fittings = vol("corners", "brackets") * 2700.0 / 1e9    # aluminium angle corner pieces and board brackets
ex0, el, ew, eh = P["enc"]
m_enc = vol("enclosure", "door") * rho + 0.3              # 0.3 kg: hinge, lock, glands, vent, doubler strips
ply = A["ply_rho"] / 1e9
m_deck = P["deck_len"] * P["deck_w"] * P["deck_t"] * ply
m_boards = (2 * P["deck_len"] + 2 * P["deck_w"]) * P["board_h"] * P["board_t"] * ply
made = {"1 Chassis frame (welded steel)": m_frame, "2 Deck, 12 mm plywood": m_deck,
        "2 Side boards, removable": m_boards, "2 Corner pieces and board brackets, aluminium": m_fittings,
        "3 Drawbar, 38 x 2.5 mm S355, bent": m_drawbar,
        "6 Coupler housing, end cap cartridge and brake lever (steel)": m_coupler,
        "10 Enclosure and door, 0.8 mm steel": m_enc, "16 Parking stand": m_stand}
say("A1", f"Frame, from the model: box section rails and crossmembers {m_box:.2f} kg; "
          f"nose bars {m_nose:.2f} kg; arch frames and tie-down eyes {m_arch:.2f} kg; dropout plates {m_plates:.2f} kg; "
          f"frame total {m_frame:.1f} kg")
for k, v in {**made, **BOUGHT}.items():
    say("A2", f"{k}: {v:.2f} kg")
m_empty = sum(made.values()) + sum(BOUGHT.values())
m_loaded = m_empty + A["payload"]
R8_CAP = 47.0   # R8: hard cap for the first prototype only (CGM-DDR-003 A1, decided 2026-10-02)
say("A3", f"Empty trailer {m_empty:.1f} kg ({m_empty*2.2046:.0f} lb) against the R8 prototype cap of {R8_CAP:.0f} kg "
          f"(35 kg at TRL 2, 40 kg by CGM-DDR-001, 45 kg by CGM-DDR-002, 47 kg cap by CGM-DDR-003 A1); "
          f"without side boards {m_empty-m_boards:.1f} kg")
say("A4", f"Loaded trailer, design case: {m_loaded:.1f} kg")
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

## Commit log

2026-09-24 Initial scaffold: standard open hardware layout, CERN-OHL-S v2 + MIT licenses
    Claude-Session: https://claude.ai/code/session_01XuhhSU4W6fYhgCfURbrkut
    [bom.csv]
2026-09-25 Adopt portfolio kit v1.3.0: session commands, scale figure, 3D viewer, flow diagrams
    Adds .claude/commands (/populate, /advance-trl3, /rein-in, /refresh-media)
    so every Claude Code session starts from the standard prompts, and extends
    concept media with a 1.75 m scale figure, an interactive glTF viewer and
    system or energy flow diagrams. TRL cap 3 unchanged.
    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
2026-09-25 Kit v1.3.1: renderer fixes from the TremorTrace pilot
    Context scale parts for small objects, cutaway exclusions, and text
    labels in flow diagrams.
    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
2026-09-25 Populate cargomule to a strong TRL 2 with concept media (batch 3)
    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
    [bom.csv]
2026-09-25 Advance cargomule to TRL 3 (batch 3)
    Decisions approved by Amish 2026-09-25 recorded in DDR-001. TRL 4 is on hold.
    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
    [bom.csv, cargomule-assembly.step, cargomule-assembly.stl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]
2026-09-26 Accept all recommendations (DDR-002), switch footer to designmolecule.com, add README write-up with new inspiration point
    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
    [bom.csv, cargomule-assembly.step, cargomule-assembly.stl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]
2026-09-27 Product appearance model and photoreal renders
    Adds cad/src/product_model.py (appearance model for renders only, all main
    dimensions from model.py) and Blender renders in media/render-*.png,
    captioned with the project, repository and viewing direction. README leads
    with the product render; trl stays 3.
    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
2026-10-01 Image quality pass: legible exploded views, flow diagrams and drawing sheets
    Kit 1.6.1 image layout: the parts list sits in its own column, number bubbles sit on visible parts and never overlap, small parts get a leader, pictures are cropped to the subject, flow labels keep numbers with their units, and sheet captions and the revision table no longer overprint. Concept images, blueprint and general arrangement sheet regenerated; repo-specific labels moved clear of other text and lines.
2026-10-01 Kit 1.7.0: constructable design, illustrated build plan and design decisions register
    The design is now constructable: every part can be made and fits its neighbours, with each change recorded in a Design for construction decision record (made under Amish's 2026-09-30 instruction; ope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
    [bom.csv, cargomule-assembly.step, cargomule-assembly.stl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]
2026-10-01 Budget treated as a value-engineering target
    Amish, 2026-10-01: the budget is a hypothetical control target that keeps the design on a value-engineering lens, not a spending limit. Documents now state the value-engineering target and the estima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
2026-10-02 Record Amish's approval of the open-decision recommendations
    Amish approved the recommendation on every open decision in the design decisions register ("i approve your recommendations for all 555 open decisions.", 2026-10-02). Each decision is moved to Decisio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
2026-10-03 Carry approved follow-ups into the design and redo photoreal renders
    Amish approved the follow-up actions from the open-decision sign-off ("APPROVED CHANGES, COMPLETE THESE", 2026-10-02), the design-for-construction change tables in ten repos, the last wave's open dec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
    [bom.csv, cargomule-assembly.step, cargomule-assembly.stl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]

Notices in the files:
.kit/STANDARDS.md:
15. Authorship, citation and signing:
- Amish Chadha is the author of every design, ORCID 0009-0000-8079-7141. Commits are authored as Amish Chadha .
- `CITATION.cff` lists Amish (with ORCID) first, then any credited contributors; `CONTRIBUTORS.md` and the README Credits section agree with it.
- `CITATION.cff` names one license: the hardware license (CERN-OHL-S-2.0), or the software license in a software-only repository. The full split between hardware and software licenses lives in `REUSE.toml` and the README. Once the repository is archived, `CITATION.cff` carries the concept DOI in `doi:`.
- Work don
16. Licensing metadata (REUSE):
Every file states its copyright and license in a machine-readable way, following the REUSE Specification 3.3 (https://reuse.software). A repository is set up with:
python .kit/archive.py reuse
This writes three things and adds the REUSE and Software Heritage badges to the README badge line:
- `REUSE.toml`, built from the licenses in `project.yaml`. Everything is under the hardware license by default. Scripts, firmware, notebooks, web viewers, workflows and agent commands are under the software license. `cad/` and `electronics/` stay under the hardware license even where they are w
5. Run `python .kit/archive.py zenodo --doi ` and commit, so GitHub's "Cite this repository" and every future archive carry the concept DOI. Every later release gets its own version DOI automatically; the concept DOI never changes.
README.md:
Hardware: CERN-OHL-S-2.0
